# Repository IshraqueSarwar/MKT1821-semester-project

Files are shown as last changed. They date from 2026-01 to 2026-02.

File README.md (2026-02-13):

# Volumetrically Optimized Obstacle Avoidance Vechical

**Course:** Introduction to mechatronics (MKT-1821) <br>
**Instructor:** Prof. Haydar Livatyali & Associate Prof Erhan akdoğan <br>
**Softwares:** Weebot, arduinoIDE, SolidWorks, CrealityPrint<br>
**Focus:** Mechanical architecture, Electronic circuits, integrated sensing & control system design <br>
**Status:** Completed  <br>

<p align="center">
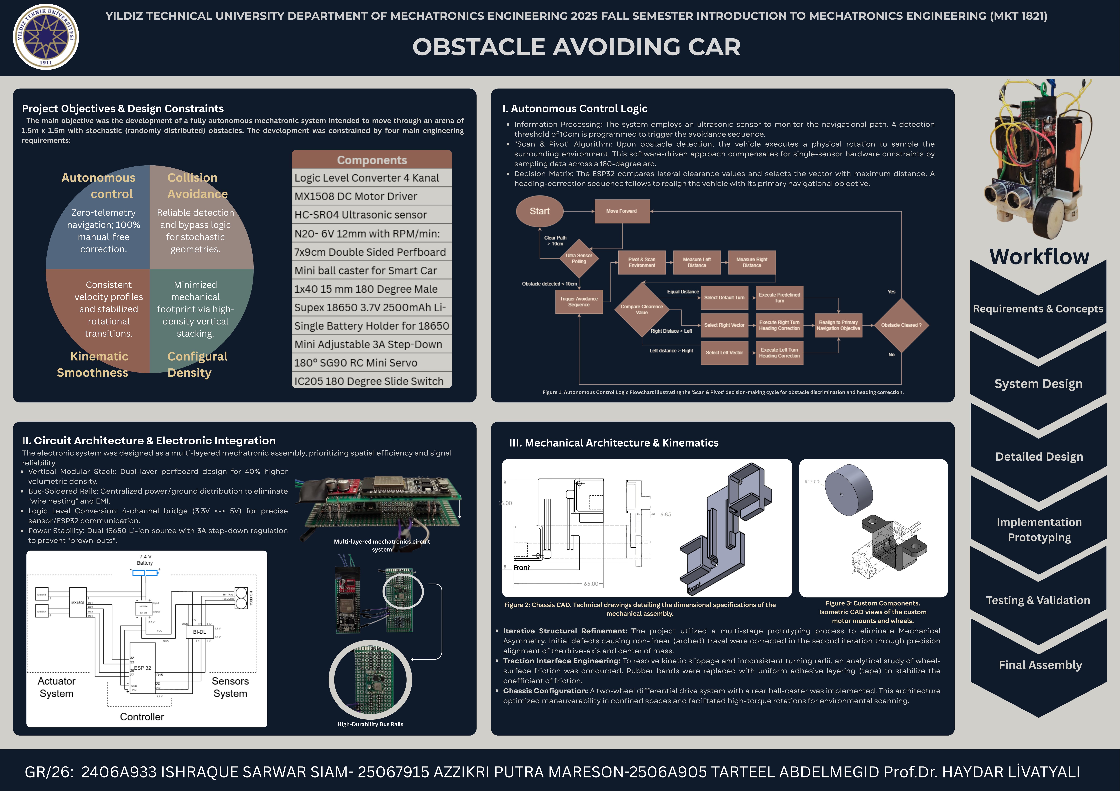
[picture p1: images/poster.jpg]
  
</p>

---

## Project Overview

It is a compact, size‑optimized obstacle‑avoidance car designed as a MEchatronics course capstone. The project emphasizes volumetric efficiency: a stacked, two‑layer electronic architecture and an overlapping motor/chassis arrangement reduce footprint while keeping components serviceable and mechanically robust. The mechanical structure was modeled and dimensioned in SolidWorks, and the electronics were implemented on a two‑layer perfboard stack to prioritize signal integrity and compactness.

This repository contains the project overview, circuit documentation, mechanical CAD deliverables, and a clear description of the onboard algorithm used for autonomous navigation.

## 🎥 Project Demonstration
<p align="center">
  
</p>

---

## Highlights

- Two‑layer stacked electronics for high volumetric density and short routing paths.
- Overlapping motor/chassis design for compact footprint and improved yaw authority in tight spaces.
- Simple, robust autonomous algorithm optimized for single‑sensor ultrasonic scanning and low computational load.
- CAD deliverables: fully dimensioned chassis drawing, isometric views, and parts for fabrication.

---

<p align="center">
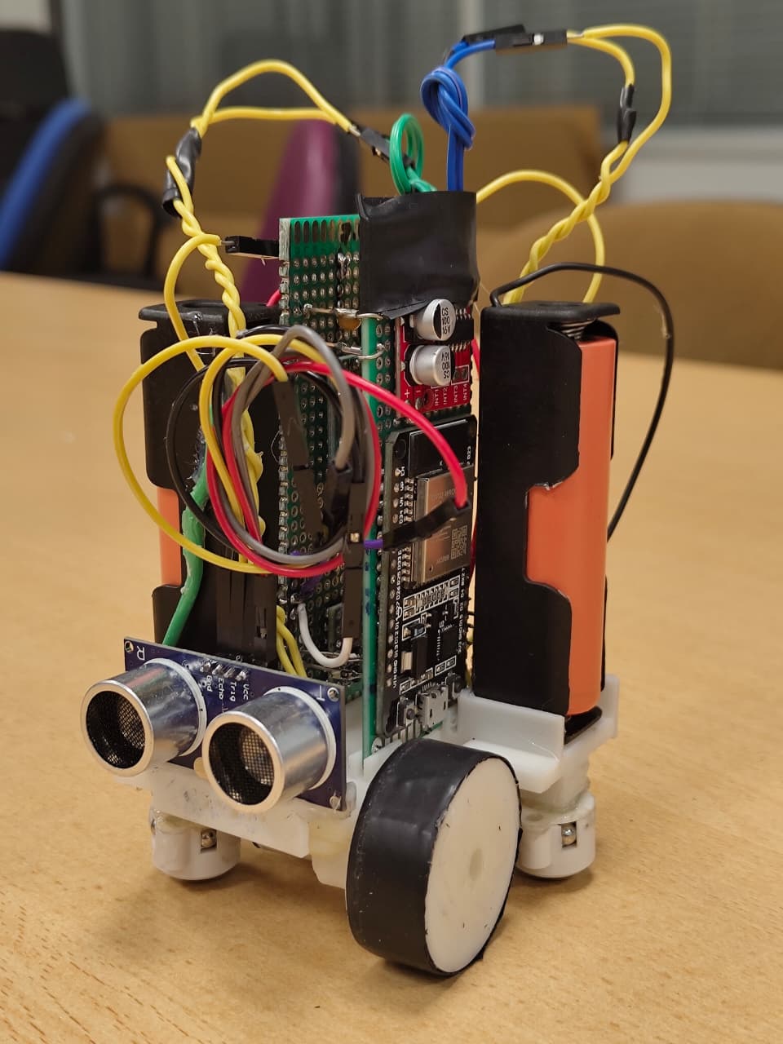
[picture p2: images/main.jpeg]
  
</p>

## 1. Mechanical Design — Chassis

### Summary
The chassis uses an overlapping motor mount concept: the drive motors are arranged so their housings partially overlap with the main body plane. This overlapping reduces overall length while preserving wheelbase and turning capability. The main chassis was modeled parametrically in SolidWorks and exported as manufacturing drawings.

<p align="center">
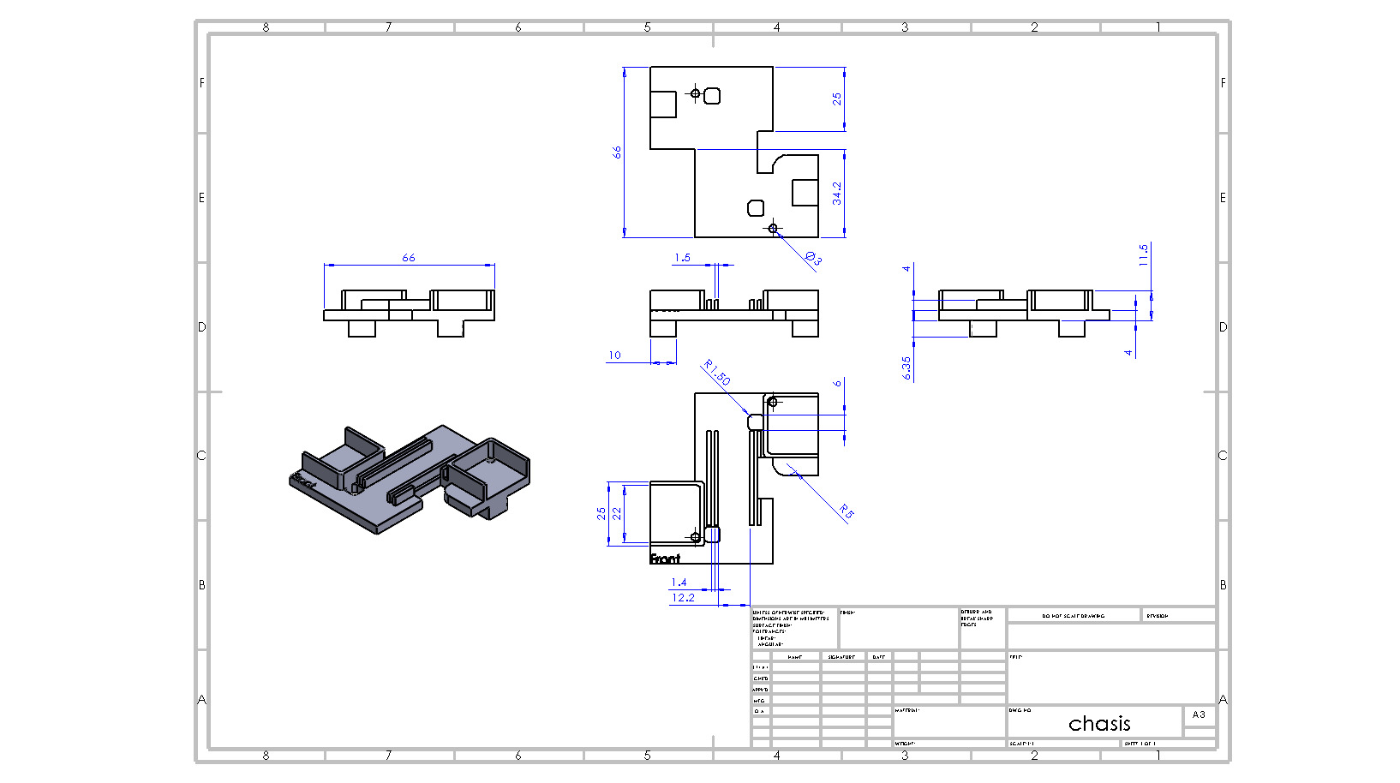
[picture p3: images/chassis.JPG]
  
</p>

### Drawings & CAD:
- Chassis technical drawing: detailed, dimensioned views and an isometric illustration of the assembly.
- Project poster (overview): high‑level poster showing system architecture, workflow, and rendered isometrics.

### Mechanical considerations
- Kinematic smoothness: the geometry was tuned to keep wheel contact and minimize sudden shifts during turning maneuvers.
- Traction & interface: traction surfaces were optimized during prototyping; the final design uses uniform adhesive strips to stabilize wheel grip without increasing slip.
- Assembly & serviceability: the chassis allows the stacked electronics to slide in/out of a slot for quick access to the controller and power modules.

---

## 2. Electrical Circuit — Stacked Architecture

### Summary
The electronic system is implemented as a vertical, two‑board stack. This approach concentrates motors, battery management, power conversion, and sensing into a compact column, dramatically reducing the vehicle's footprint while keeping wiring short to lower noise and latency.

### Visuals:

<p align="center">
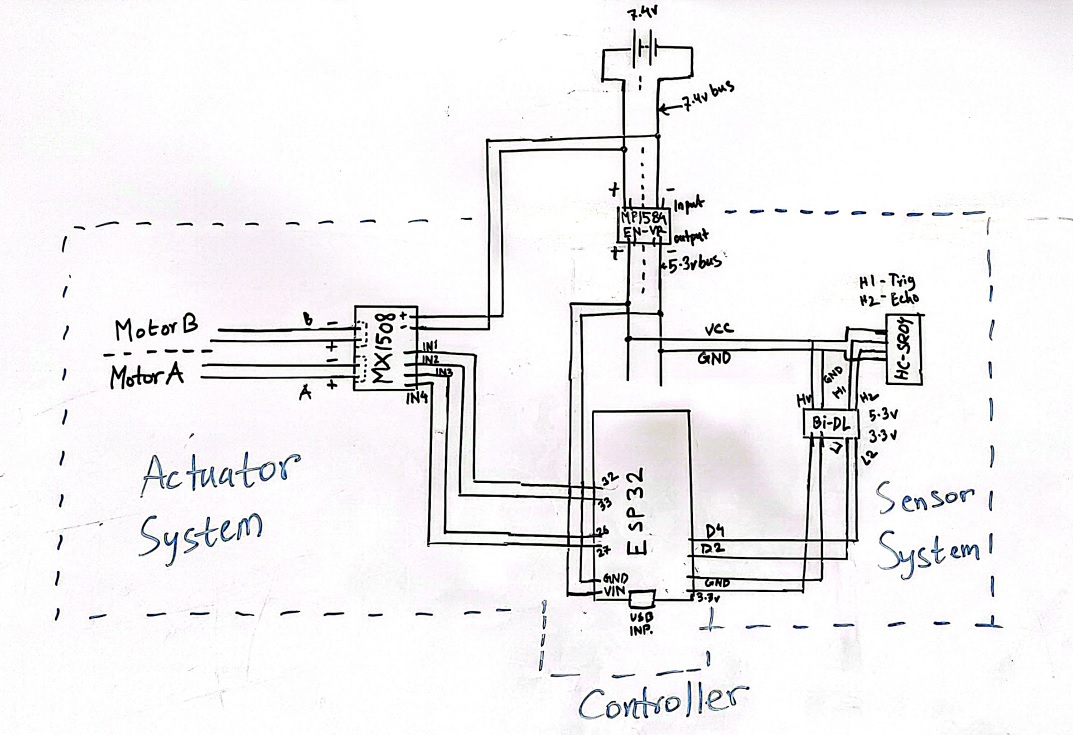
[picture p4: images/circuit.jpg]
  
</p>
simplified schematic that documents power rails, motor driver connections (MX1508), the ultrasonic sensor (HC‑SR04), and the ESP32 control pins.

<p align="center">
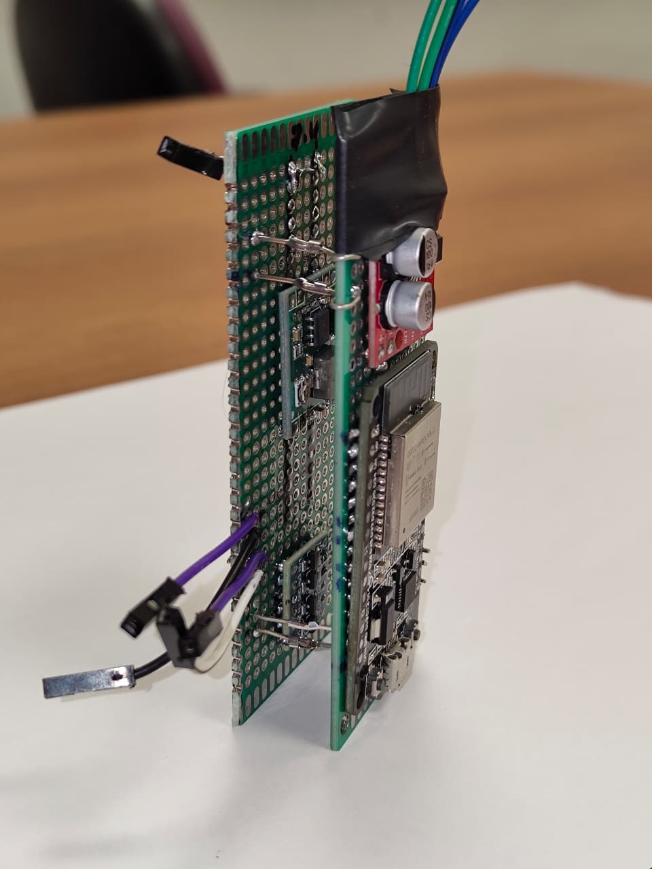
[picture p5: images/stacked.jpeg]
  
</p>
shows the physical arrangement of the ESP32 controller, step‑down regulator, and motor driver modules mounted on two stacked perfboards.

<p align="center">
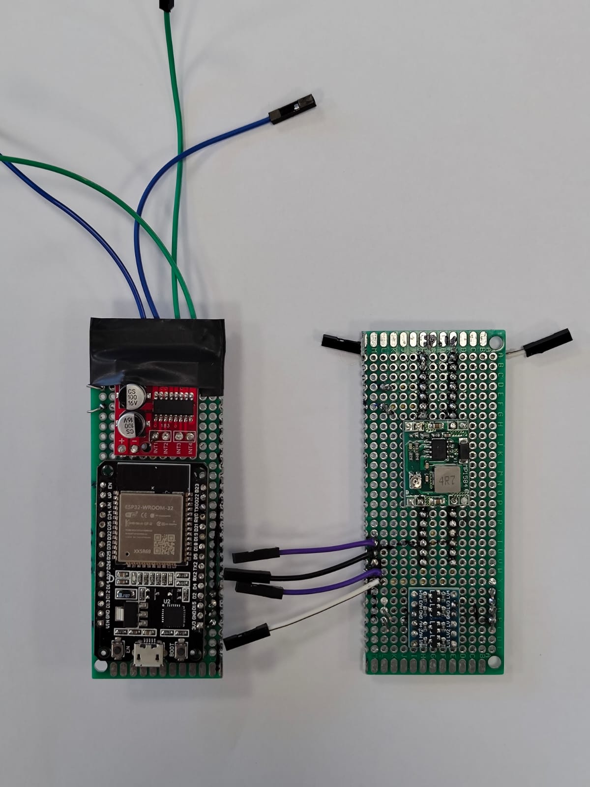
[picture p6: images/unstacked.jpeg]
  
</p>
shows the two layers separated for clarity (controller layer and actuator/sensor layer).

---

## 3. Algorithm — Autonomous Control Logic

### Summary
The control algorithm implements a low‑compute, reliable avoidance strategy designed for single ultrasonic sensor hardware constraints. It uses a simple Scan & Pivot method: when an obstacle is detected within a safety threshold, the vehicle samples left and right clearance and selects the direction with greater free space.

### Flowchart:
<p align="center">
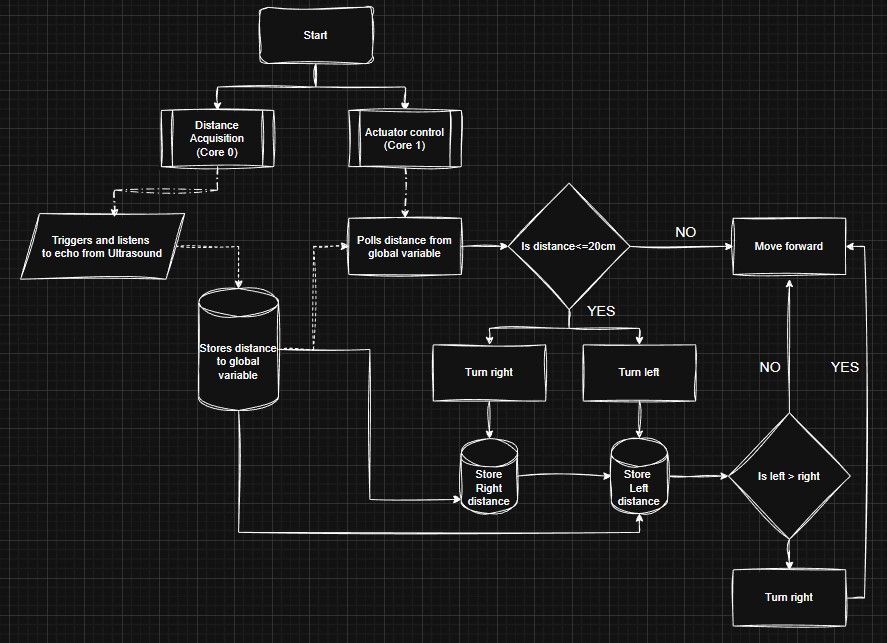
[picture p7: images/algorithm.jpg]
  
</p>

### Algorithm (stepwise)
1. Distance Acquisition (Sensor Core): the ultrasonic sensor is triggered and the echo time is measured. The measured distance is stored in a global variable accessible to the actuator core.
2. Actuator Control (Actuator Core): the actuator routine polls the global distance variable at a fixed control rate and decides navigation commands.
3. Threshold check: if measured distance ≤ 20 cm, the avoidance routine is triggered. Otherwise the vehicle proceeds with forward motion.
4. Scan & Pivot sequence:
	- Pivot the vehicle in place toward one side (e.g., right) and sample the distance.
	- Return to center, pivot the opposite side (left) and sample the distance.
	- Compare left and right distances.
	- Select the direction with greater clearance and execute a predefined turning maneuver to re‑align the vehicle with its primary navigation objective.
	Resume forward motion once the path ahead is clear.

### Implementation notes: 
- The control loop is split into two cores (sensor acquisition and actuation) to take advantage of the RTOS separation (using the two esp cores, one of the reasons for selecting esp microcontroller) and keep latency low.
- The algorithm prioritizes simplicity and determinism to work on low‑power microcontrollers (ESP32) and under stochastic obstacle distributions.

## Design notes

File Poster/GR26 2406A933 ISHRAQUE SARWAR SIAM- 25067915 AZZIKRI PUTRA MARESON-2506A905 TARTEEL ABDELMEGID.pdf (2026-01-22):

YILDIZ TECHNICAL UNIVERSITY DEPARTMENT OF MECHATRONICS ENGINEERING 2025 FALL SEMESTER INTRODUCTION TO MECHATRONICS ENGINEERING (MKT 1821)

# OBSTACLE AVOIDING CAR

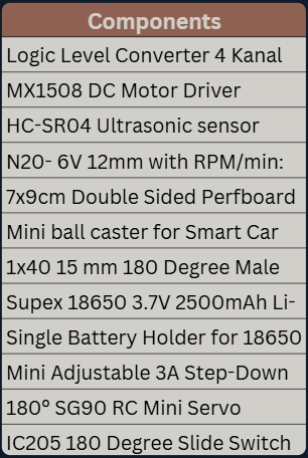
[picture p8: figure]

Autonomous control Zero-telemetry navigation; 100% manual-free correction. | Collision Avoidance Reliable detection and bypass logic for stochastic geometries.

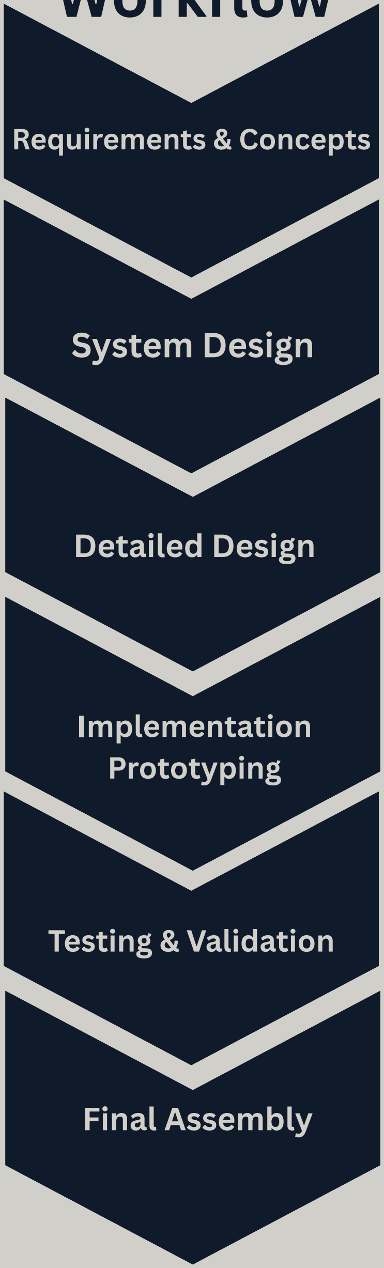
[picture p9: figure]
Requirements & Concepts; System Design; Detailed Design; Implementation Prototyping; Testing & Validation; Final Assembly

Consistent velocity profiles and stabilized rotational transitions. Kinematic | Minimized mechanical footprint via high-density vertical stacking. Configural

## Smoothness Density

## I. Autonomous Control Logic

Information Processing: The system employs an ultrasonic sensor to monitor the navigational path. A detection threshold of 10cm is programmed to trigger the avoidance sequence.
"Scan & Pivot" Algorithm: Upon obstacle detection, the vehicle executes a physical rotation to sample the surrounding environment. This software-driven approach compensates for single-sensor hardware constraints by sampling data across a 180-degree arc.
Decision Matrix: The ESP32 compares lateral clearance values and selects the vector with maximum distance. A heading-correction sequence follows to realign the vehicle with its primary navigational objective.

## Project Objectives & Design Constraints

The main objective was the development of a fully autonomous mechatronic system intended to move through an arena of 1.5m x 1.5m with stochastic (randomly distributed) obstacles. The development was constrained by four main engineering requirements:

Figure 1: Autonomous Control Logic Flowchart illustrating the 'Scan & Pivot' decision-making cycle for obstacle discrimination and heading correction.

## II. Circuit Architecture & Electronic Integration

The electronic system was designed as a multi-layered mechatronic assembly, prioritizing spatial efficiency and signal reliability.

High-Durability Bus Rails

Multi-layered mechatronics circuit system

Vertical Modular Stack: Dual-layer perfboard design for 40% higher volumetric density.
Bus-Soldered Rails: Centralized power/ground distribution to eliminate "wire nesting" and EMI.
Logic Level Conversion: 4-channel bridge (3.3V <-> 5V) for precise sensor/ESP32 communication.
Power Stability: Dual 18650 Li-ion source with 3A step-down regulation to prevent "brown-outs"

Figure 2: Chassis CAD. Technical drawings detailing the dimensional specifications of the
mechanical assembly.

## III. Mechanical Architecture & Kinematics

Iterative Structural Refinement: The project utilized a multi-stage prototyping process to eliminate Mechanical Asymmetry. Initial defects causing non-linear (arched) travel were corrected in the second iteration through precision alignment of the drive-axis and center of mass.
Traction Interface Engineering: To resolve kinetic slippage and inconsistent turning radii, an analytical study of wheelsurface friction was conducted. Rubber bands were replaced with uniform adhesive layering (tape) to stabilize the coefficient of friction.
Chassis Configuration: A two-wheel differential drive system with a rear ball-caster was implemented. This architecture optimized maneuverability in confined spaces and facilitated high-torque rotations for environmental scanning.

Figure 3: Custom Components. Isometric CAD views of the custom motor mounts and wheels.

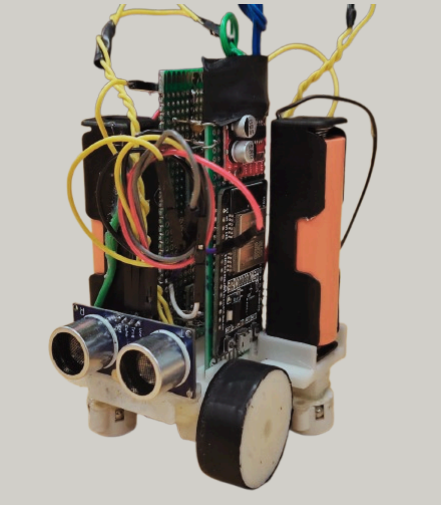
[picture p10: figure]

# Workflow

GR/26: 2406A933 ISHRAQUE SARWAR SIAM- 25067915 AZZIKRI PUTRA MARESON-2506A905 TARTEEL ABDELMEGID Prof.Dr. HAYDAR LİVATYALI

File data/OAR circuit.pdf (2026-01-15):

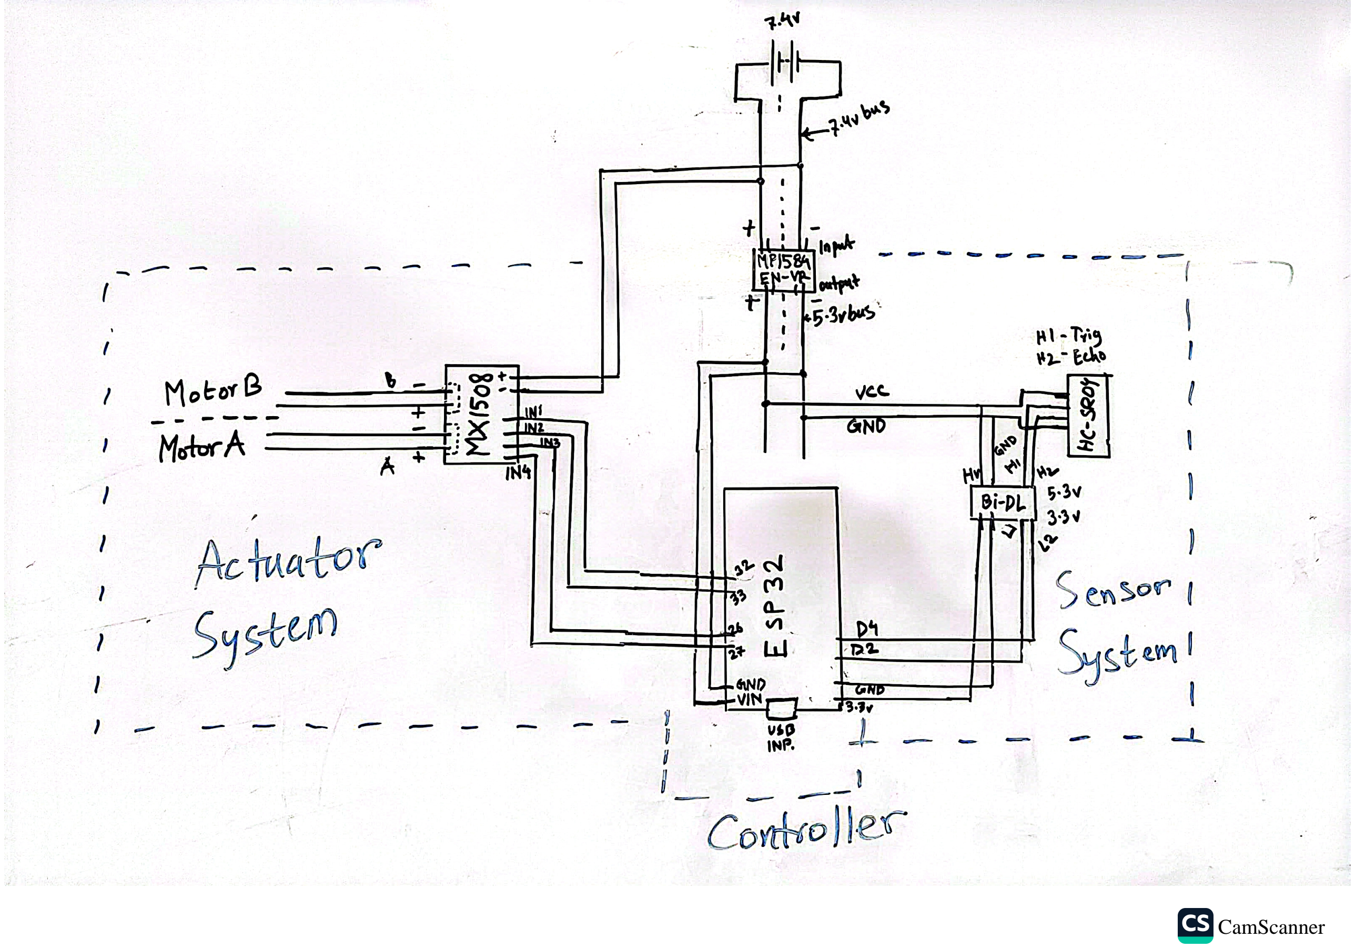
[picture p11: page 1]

CamScanner (https://v3.camscanner.com/user/download)

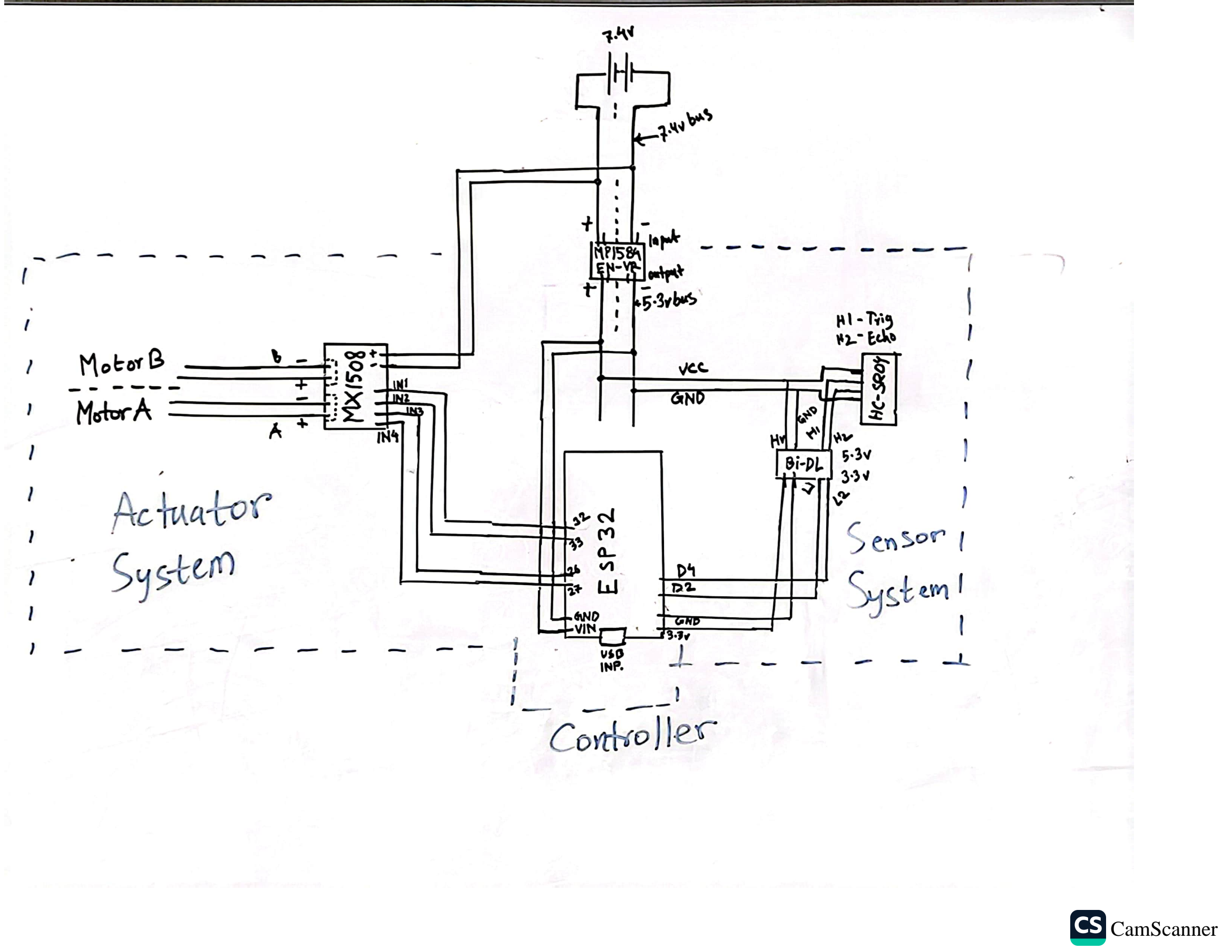
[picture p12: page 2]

CamScanner (https://v3.camscanner.com/user/download)

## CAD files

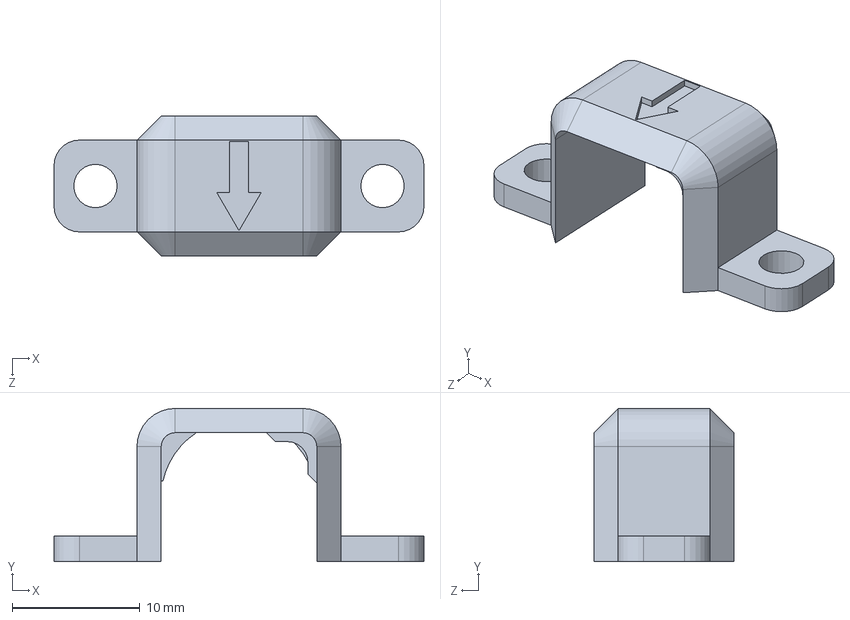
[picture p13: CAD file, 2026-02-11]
models/n20 motor bracket.SLDPRT
29.0 x 12.0 x 11.0 mm

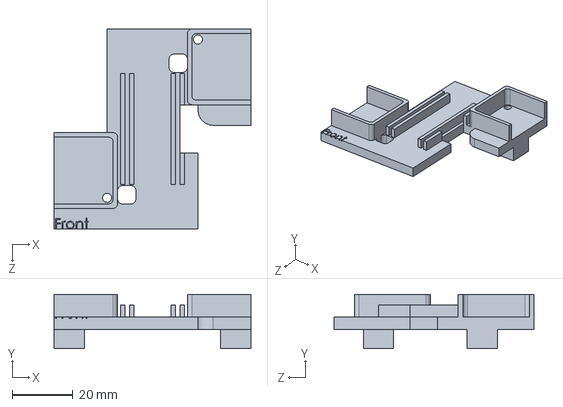
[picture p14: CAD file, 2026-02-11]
models/chasis.SLDPRT
65.0 x 17.9 x 66.0 mm

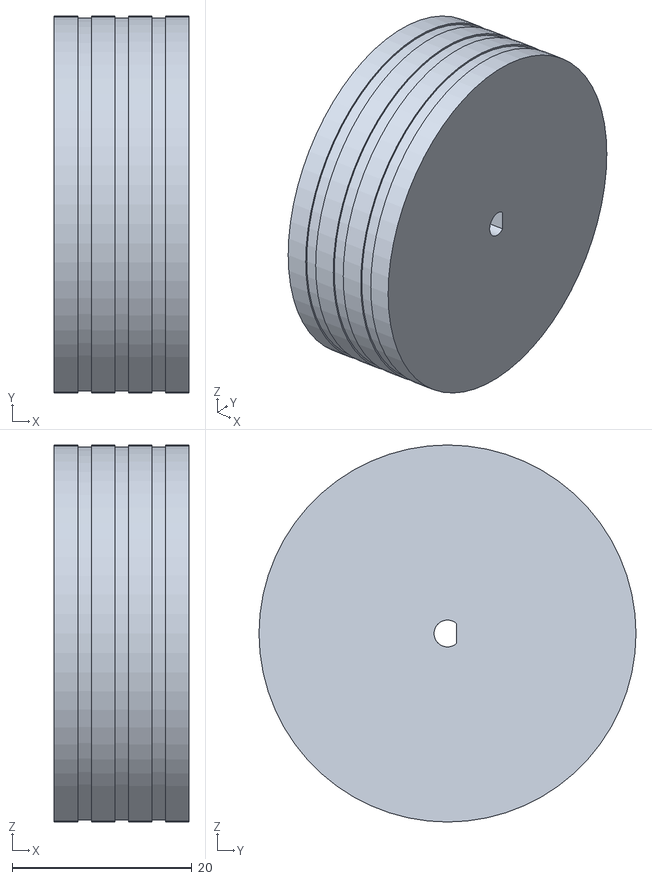
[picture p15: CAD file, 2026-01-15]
models/Print/wheelff.STL
15.0 x 42.0 x 42.0

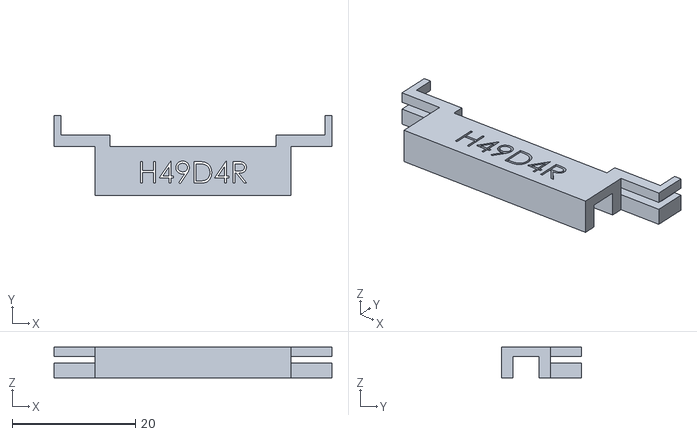
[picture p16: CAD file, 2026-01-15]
models/Print/clanker.STL
45.1 x 13.0 x 5.00

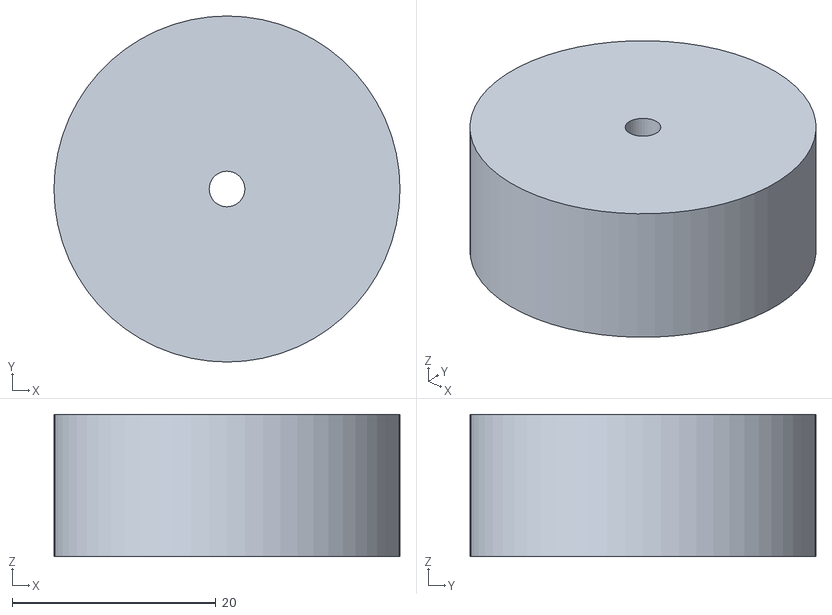
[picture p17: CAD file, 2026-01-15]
models/Print/wheel_v4.STL
34.0 x 34.0 x 14.0

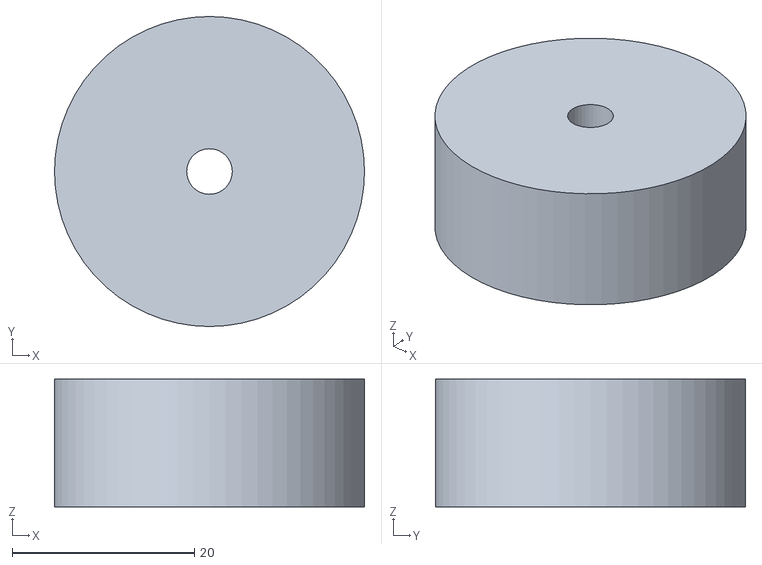
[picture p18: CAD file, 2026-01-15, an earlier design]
models/Print/wheel_v3.STL
34.0 x 34.0 x 14.0

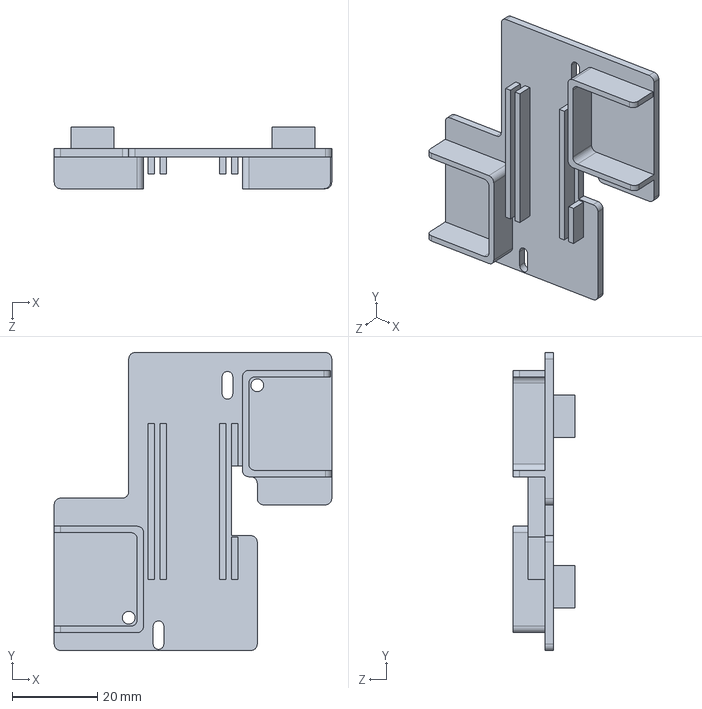
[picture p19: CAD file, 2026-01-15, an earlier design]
models/chasis-v1.SLDPRT
65.2 x 70.0 x 14.4 mm

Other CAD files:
models/Sensor bracket.SLDPRT
models/chasis-v2.SLDPRT
models/Print/chasis.STL
models/Print/n20_motor_bracket.stl
models/technical drawing/chasis.SLDDRW

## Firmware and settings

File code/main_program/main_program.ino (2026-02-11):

#include <Arduino.h>


// Transducer structure, used both for the actuator and the sensor
struct Transducer{
  int pin_1;
  int pin_2;
};


// actuator pin initialization
const Transducer top_left_motor = {27, 26};
const Transducer bottom_right_motor = {33, 32};
const int list_of_all_motor_pins[] = {26, 27, 32, 33};


// sensor pin initialization
// pin_1(15)->trigger pin
// pin_2(2)->echo pin
const Transducer ultrasound_sensor = {15, 2}; 


// --- Thresholds, Constants & shared variables ---
const int DISTANCE_THRESHOLD = 20;
const int NUMBER_OF_MOTOR_PINS = 4;

volatile int shared_distance = 999;
volatile bool pause_backgound_sensing = false; 

// --- Settings ---
const int motor_speed_while_turning = 100; // range of speed(0-255)
const int motor_speed_while_moving = 85; // range of speed(0-255)
const int min_startup_speed = 40;
const int rotation_time = 300; // in millisecond
const int pause_time = 2000; // time the bot pauses between turns(in milliseconds)
const int pwm_freq = 5000; // 5kHz
const int pwm_resolution = 8; // 8-bits resolution(0-255)
const int ramp_delay = 5; // 5 ms delay between ramping up the speed
const int turn_speed_delta = 2; // speed ramp up delta


// --- Function Prototypes --- 
void setup_pwm_for_motors();
void rotate_right();
void rotate_left();
void move_forward();
void move_backward();
void stop_motors();
int read_distance();
int read_filtered_distance();
void avoid_obstacle();
void test_turns();


// main setup function that is called when the computer boots
void setup(){
  // setup the serial port with baud rate of 115200
  Serial.begin(115200);

  //initializing pins for sensor
  pinMode(ultrasound_sensor.pin_1, OUTPUT); // Trigger-> pin_1-> 15-> output
  pinMode(ultrasound_sensor.pin_2, INPUT_PULLUP); //Echo-> pin_2-> 2->Input


  // initalizing the pwm motors by calling the initialization function
  setup_pwm_for_motors();

  // start the motors at stopped state
  stop_motors();

  // printing initialization statements
  Serial.println("H49D4R bot initialized!");
  Serial.println("Core computer: ESP32");
  Serial.println("Program by: MrRobot");
  Serial.println("-------------------------");
  delay(2000); 

}


// --- Shared variable for scatter protection ---
// Place this just above void loop() or with your other global variables
int previous_distance = 999;
const int MAX_JUMP = 20; // If distance jumps > 20cm instantly, ignore it

// the main loop function
void loop(){
  // 1. Get the raw filtered reading
  int raw_distance = read_filtered_distance();
  int effective_distance = raw_distance;

  // --- REFLECTION & SCATTER GUARD ---
  
  // Check if we were recently close to a wall (< 25cm)
  bool was_close = (previous_distance < 25);

 
  bool sudden_spike = (raw_distance > previous_distance + MAX_JUMP);
  if(raw_distance == 999 && was_close) sudden_spike = true;

  if (was_close && sudden_spike) {
      Serial.print("Scatter/Reflection detected! Raw: ");
      Serial.print(raw_distance);
      Serial.println(" -> Ignored. Using previous.");
      
      // Override: Trust the previous "dangerous" distance
      effective_distance = previous_distance; 
  } else {
      
      if(raw_distance != 999) {
        previous_distance = raw_distance;
      }
  }
  // ----------------------------------

  Serial.print("Distance: ");
  Serial.print(effective_distance);
  Serial.println(" cm");

  // Use 'effective_distance' for the logic check
  if(effective_distance < DISTANCE_THRESHOLD){
    Serial.println("obstacle");
    stop_motors();
    avoid_obstacle();

    // Reset history so we don't get stuck in a loop after turning
    previous_distance = 999; 
  }else{
    Serial.println("clear");
    move_forward();
  }

  delay(100);
}


void test_turns(){
  int pause_time = 500;

  stop_motors();

  // scan left
  rotate_left();
  delay(rotation_time);
  stop_motors();
  delay(pause_time);

  rotate_right();
  delay(rotation_time);
  stop_motors();
  delay(pause_time);
  //second rotation looks to the right
  rotate_right();
  delay(rotation_time);
  stop_motors();

}


// pwm_setup function configures pwm for the motors
void setup_pwm_for_motors(){
  for(int i = 0;i<NUMBER_OF_MOTOR_PINS;i++){
    ledcAttach(list_of_all_motor_pins[i], pwm_freq, pwm_resolution);
  }
}

// function that halts all the motors
void stop_motors(){
  for(int i = 0;i<NUMBER_OF_MOTOR_PINS;i++){
    ledcWrite(list_of_all_motor_pins[i], 0);
  }
}

void move_forward(){
  // front motor forward
  ledcWrite(top_left_motor.pin_1, motor_speed_while_moving);
  ledcWrite(top_left_motor.pin_2, 0);
  //back motor forward
  ledcWrite(bottom_right_motor.pin_1, motor_speed_while_moving);
  ledcWrite(bottom_right_motor.pin_2, 0);

}

void move_backward(){
  //front wheel backward
  ledcWrite(top_left_motor.pin_1, 0);
  ledcWrite(top_left_motor.pin_2, motor_speed_while_moving);

  //back motor backward
  ledcWrite(bottom_right_motor.pin_1, 0);
  ledcWrite(bottom_right_motor.pin_2, motor_speed_while_moving);
}


void rotate_right(){
  // front motor forward
  for (int speed = min_startup_speed; speed <= motor_speed_while_turning; speed += turn_speed_delta){
    ledcWrite(top_left_motor.pin_1, speed);
    ledcWrite(top_left_motor.pin_2, 0);

    //back motor backward
    ledcWrite(bottom_right_motor.pin_1, 0);
    ledcWrite(bottom_right_motor.pin_2, speed);
    // ramp up the speed gradually
    delay(ramp_delay);
  }
  
}

void rotate_left(){
  for (int speed = min_startup_speed; speed <= motor_speed_while_turning; speed += turn_speed_delta){
    // front motor backward
    ledcWrite(top_left_motor.pin_1, 0);
    ledcWrite(top_left_motor.pin_2, speed);

    //back motor forword
    ledcWrite(bottom_right_motor.pin_1, speed);
    ledcWrite(bottom_right_motor.pin_2, 0);
  }
}

// function that reads the distance using ultrasound sensor
int read_distance(){
  //clear the trigger
  digitalWrite(ultrasound_sensor.pin_1, LOW);
  delayMicroseconds(2);

  // send 10 microsecond pulse
  digitalWrite(ultrasound_sensor.pin_1, HIGH);
  delayMicroseconds(10);
  digitalWrite(ultrasound_sensor.pin_1, LOW);

  // get the duration it took for the pulses to make back
  long duration = pulseIn(ultrasound_sensor.pin_2, HIGH, 30000);

  if(!duration){
    return 999;
  }
  return (int)(duration*0.0343/2);
}

// function to remove noise from raw sensor data
int read_filtered_distance(){
  int reading_1 = read_distance();
  delay(2);
  int reading_2 = read_distance();
  delay(2);
  int reading_3 = read_distance();

  // sorting it mannually to get the mid value
  if(reading_1 > reading_2){ int temp = reading_1; reading_1 = reading_2; reading_2 = temp;}
  if(reading_2 > reading_3){ int temp = reading_2; reading_2 = reading_3; reading_3 = temp;}
  if(reading_1 > reading_2){ int temp = reading_1; reading_1 = reading_2; reading_2 = temp;}
  
  // sorted vals reading_1< reading_2< reading_3
  return reading_2;
}

void avoid_obstacle(){
  int pause_time = 500;
  Serial.println("Engaging in avoidance maneuver");

  // safety backup
  stop_motors();
  delay(700);
  move_backward();
  delay(500);
  stop_motors();
  delay(500);

  // scan left
  rotate_left();
  delay(rotation_time);
  stop_motors();
  delay(pause_time);
  int left_dist = read_filtered_distance();

  //rotate right
  // first rotation makes it face the initial direction
  rotate_right();
  delay(rotation_time);
  stop_motors();
  delay(pause_time);
  //second rotation looks to the right
  rotate_right();
  delay(rotation_time);
  stop_motors();
  delay(pause_time);
  int right_dist = read_filtered_distance();

  if(left_dist>right_dist){
    rotate_left();
    delay(rotation_time);
    stop_motors();
    delay(pause_time);

    // second time to actually rotate to left
    rotate_left();
    delay(rotation_time);
    stop_motors();
    delay(pause_time);
  }

  delay(500);

}

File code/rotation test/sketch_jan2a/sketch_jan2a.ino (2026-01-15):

/*
 * Simple Rotation Test for 2-Motor Robot (ESP32 Core 3.x Compatible)
 * Hardware Setup:
 * - MX1508 Motor A (Left) -> Pins 27, 26
 * - MX1508 Motor B (Right) -> Pins 33, 32
 * 
 * Rotation Logic:
 * - Rotate Right: Left motor forward, Right motor backward
 * - Rotate Left: Left motor backward, Right motor forward
 */

#include <Arduino.h>

// --- PIN DEFINITIONS ---
// Motor A (Left)
const int MOTOR_A_IN1 = 27; 
const int MOTOR_A_IN2 = 26;

// Motor B (Right)
const int MOTOR_B_IN1 = 33; 
const int MOTOR_B_IN2 = 32;

// PWM Settings
const int pwmFreq = 5000;      // 5 KHz frequency
const int pwmResolution = 8;   // 8-bit resolution (0-255)

// --- SETTINGS ---
const int motorSpeed = 100;      // Speed (0-255), adjust as needed
const int rotationTime = 300;   // How long to rotate (milliseconds)
const int pauseTime = 2000;      // Pause between rotations (milliseconds)

// --- FUNCTION PROTOTYPES ---
void rotateRight();
void rotateLeft();
void stopMotors();

void setup() {
  Serial.begin(115200);
  
  // Configure PWM for each motor pin (ESP32 Core 3.x API)
  ledcAttach(MOTOR_A_IN1, pwmFreq, pwmResolution);
  ledcAttach(MOTOR_A_IN2, pwmFreq, pwmResolution);
  ledcAttach(MOTOR_B_IN1, pwmFreq, pwmResolution);
  ledcAttach(MOTOR_B_IN2, pwmFreq, pwmResolution);
  
  // Make sure motors start stopped
  stopMotors();
  
  Serial.println("Robot Rotation Test Started!");
  Serial.println("Using ESP32 Core 3.x PWM API");
  Serial.println("----------------------------");
  delay(2000); // Initial 2 second delay before starting
}

void loop() {
  // // Rotate Right
  // Serial.println("MOVING RIGHT");
  // rotateRight();
  // delay(rotationTime);
  
  // // Stop briefly
  // stopMotors();
  // delay(pauseTime);
  
  // // Rotate Left
  // Serial.println("MOVING LEFT");
  // rotateLeft();
  // delay(rotationTime);
  
  // // Stop briefly
  // stopMotors();
  // delay(pauseTime);
  
  // Serial.println("---"); // Separator for readability


  // sweep function
  sweep180();
}

// --- ROTATION FUNCTIONS ---

void rotateRight() {
  // Left Motor Forward (to rotate right)
  ledcWrite(MOTOR_A_IN1, motorSpeed);
  ledcWrite(MOTOR_A_IN2, 0);
  
  // Right Motor Backward (to rotate right)
  ledcWrite(MOTOR_B_IN1, 0);
  ledcWrite(MOTOR_B_IN2, motorSpeed);
}

void rotateLeft() {
  // Left Motor Backward (to rotate left)
  ledcWrite(MOTOR_A_IN1, 0);
  ledcWrite(MOTOR_A_IN2, motorSpeed);
  
  // Right Motor Forward (to rotate left)
  ledcWrite(MOTOR_B_IN1, motorSpeed);
  ledcWrite(MOTOR_B_IN2, 0);
}

void sweep180(){
  // Rotate Right
  Serial.println("MOVING RIGHT");
  rotateRight();
  delay(rotationTime);
  
  // Stop briefly
  stopMotors();
  delay(pauseTime);
  
  // Rotate Left
  Serial.println("MOVING LEFT");
  rotateLeft();
  delay(rotationTime);
  
  // Stop briefly
  stopMotors();
  delay(pauseTime);

  // Rotate Left
  Serial.println("MOVING LEFT");
  rotateLeft();
  delay(rotationTime);

  // Stop briefly
  stopMotors();
  delay(pauseTime);


  Serial.println("MOVING RIGHT");
  rotateRight();
  delay(rotationTime);

  // Stop briefly
  stopMotors();
  delay(pauseTime);
  
  Serial.println("---"); // Separator for readability
}

void stopMotors() {
  ledcWrite(MOTOR_A_IN1, 0);
  ledcWrite(MOTOR_A_IN2, 0);
  ledcWrite(MOTOR_B_IN1, 0);
  ledcWrite(MOTOR_B_IN2, 0);
}
